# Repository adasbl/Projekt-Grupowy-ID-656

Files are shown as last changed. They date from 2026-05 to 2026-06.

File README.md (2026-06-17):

# Dron kołowy do autonomicznego mapowania terenu

Projekt autonomicznego robota mobilnego opartego na układzie różnicowym (differential drive). Projekt został zrealizowany we współpracy z [Zakładem Automatyki i Urządzeń Pomiarowych AREX Sp. z o.o](https://www.wbgroup.pl/arex/) w ramach Projektu Grupowego na Wydziale ETI Politechniki Gdańskiej.

<div align="center">
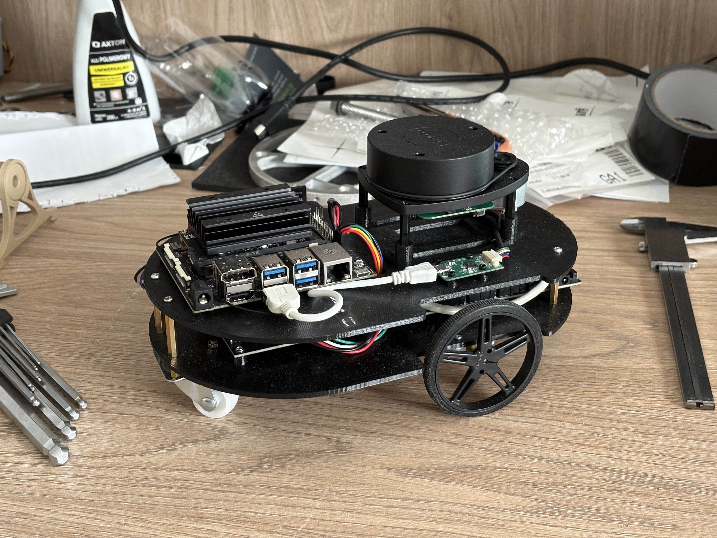
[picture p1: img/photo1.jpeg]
    
</div>

---

Głównym zadaniem robota jest autonomiczna eksploracja nieznanych przestrzeni, budowanie map (SLAM) w czasie rzeczywistym oraz omijanie przeszkód, a także możliwość zdalnego sterowania i monitorowania parametrów telemetrycznych.

<div align="center">
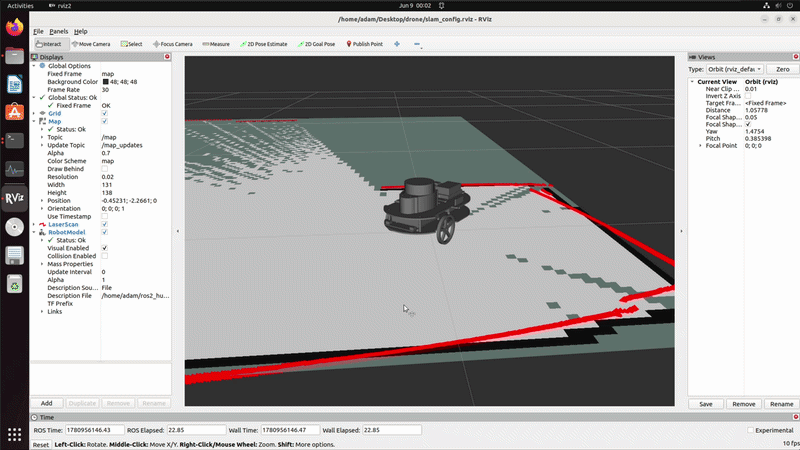
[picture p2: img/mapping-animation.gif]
    
</div>

## 🛠️ Architektura Sprzętowa (Hardware)

System został podzielony na warstwę decyzyjną (High-Level) oraz wykonawczą (Low-Level).

### Jednostka Nadrzędna (High-Level)
* **Komputer:** Nvidia Jetson Nano
* **Zadania:** Przetwarzanie danych ze skanera laserowego, działanie systemu **ROS2 (Humble)** w środowisku Docker, planowanie trajektorii, algorytmy mapowania (SLAM) oraz komunikacja Wi-Fi ze stacją bazową.
* **Sensoryka:** RPlidar A1M8-R6 (skaner laserowy 2D o zasięgu do 12m, komunikacja USB-UART).

### Jednostka Wykonawcza (Low-Level)
* **Mikrokontroler:** STM32L476RG zamontowany na [autorskiej płycie głównej](https://github.com/adasbl/main-controller-pcb.git).
* **Zadania:** Bezpośrednia kontrola silników, sprzętowy regulator PI, akwizycja danych z enkoderów oraz wymiana ramek telemetrycznych z Jetsonem po magistrali UART.
* **Napęd:** Silniki DC 6V Pololu z przekładnią 298:1, sterownik silników DRV8833.
* **Sensoryka:** * Enkodery magnetyczne Pololu 3081 (12 impulsów na obrót).
  * IMU LSM6DSV16X (akcelerometr + żyroskop po I2C do korekcji orientacji).
* **Zasilanie:** Pakiet ogniw 18650 Li-Ion (3.6V) podłączony do modułu UPS Waveshare 18307, który stabilizuje napięcie do 5V (dla Jetsona) i 3.3V (dla logiki STM32 i enkoderów).

<div align="center">
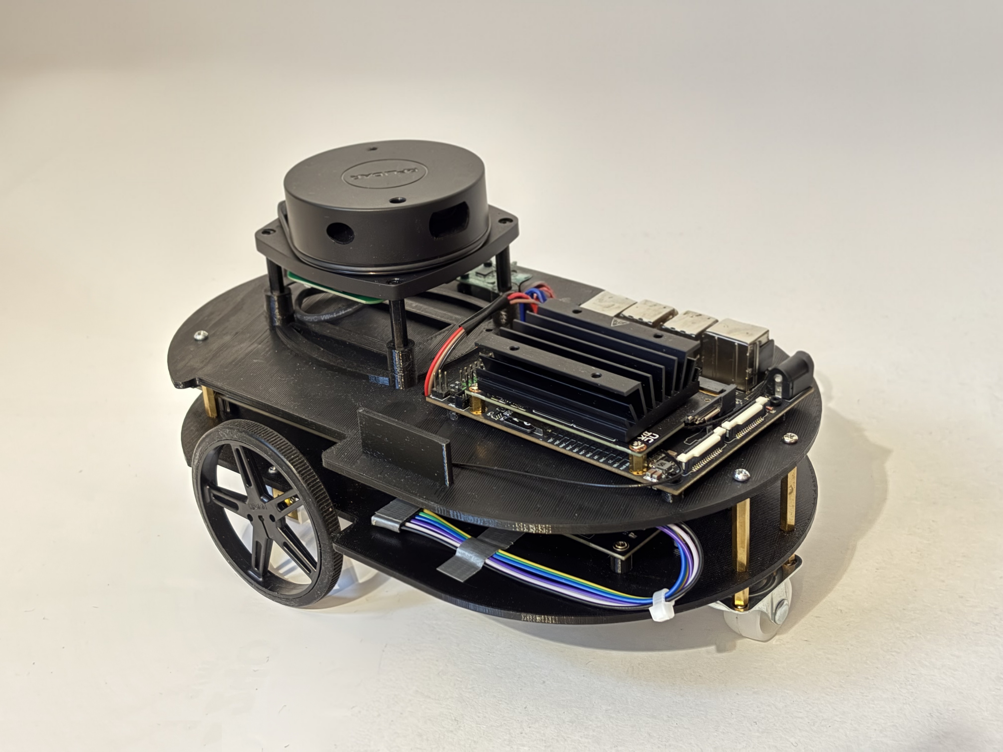
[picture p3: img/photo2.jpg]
    
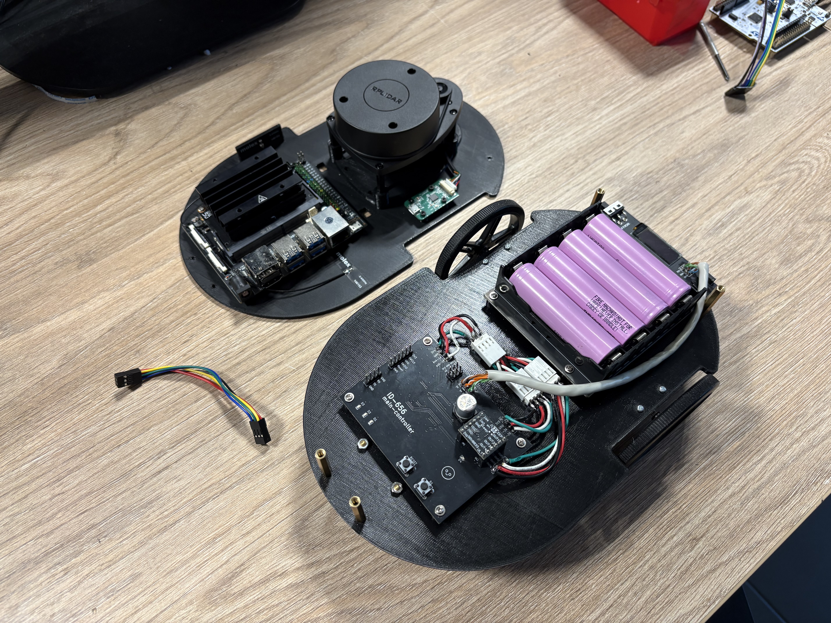
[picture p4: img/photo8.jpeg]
    
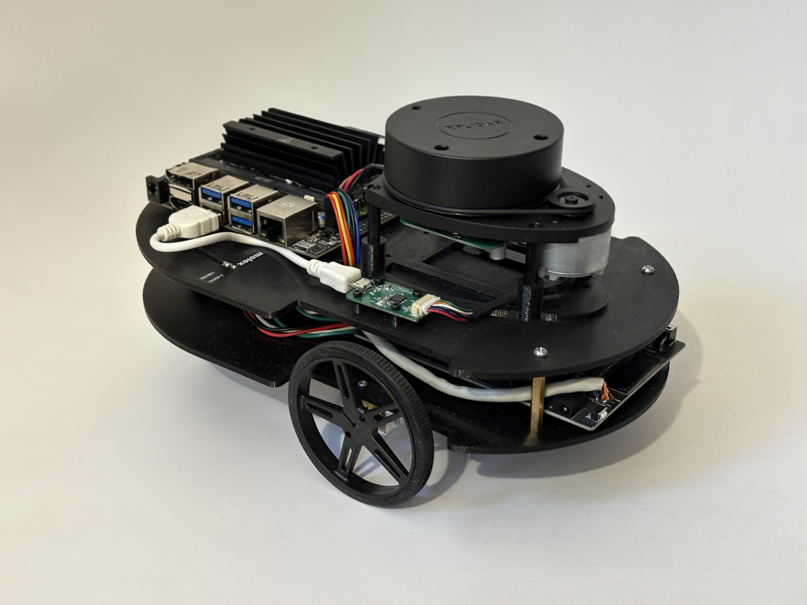
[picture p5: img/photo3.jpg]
    
</div>

---

## 🧠 Architektura Programowa (Software)

### ROS2 & Algorytmy Nawigacji (Jetson Nano)
Oprogramowanie wykorzystuje narzędzia systemu ROS2 do zarządzania węzłami.
* **Mapowanie (SLAM):** Tworzenie map w czasie rzeczywistym na podstawie odczytów z LiDARa oraz enkodometrii.
* **Nawigacja Globalna:** Autorska implementacja algorytmu **A*** (`a_star.py`) wykorzystująca heurystykę odległości Manhattan do wyznaczania najkrótszej ścieżki do celu lub integracja z planerem `GridBased` w Nav2.
* **Nawigacja Lokalna:** Algorytm **DWA (Dynamic Window Approach)** (`dwa.py`) lub `DWBLocalPlanner`, omijający dynamiczne przeszkody na bieżąco, z wbudowanym systemem wykrywania "utknięć" (stuck recovery).
* **Eksploracja:** System potrafi autonomicznie wyszukiwać najdalsze nieodkryte granice mapy (tzw. frontiers) i kierować tam robota (m.in. przy użyciu pakietu `explore_lite`).

### Low-Level Control (STM32)
* Napisany w języku C program z **regulatorem PI**
* Obsługa enkoderów, silników (sterownik `DRV8833`), czujników IMU `LSM6DSV16X` (I2C), przycisków i diód, komunikacji UART
* Komunikacja z Jetsonem odbywa się za pomocą asynchronicznych ramek UART o stałej długości 10 bajtów: `[0xAA, v_lin(float), v_ang(float), 0x55]`.
* Przelicza zadane prędkości na m/s na ticki enkoderów w cyklu 25 ms.

<div align="center">
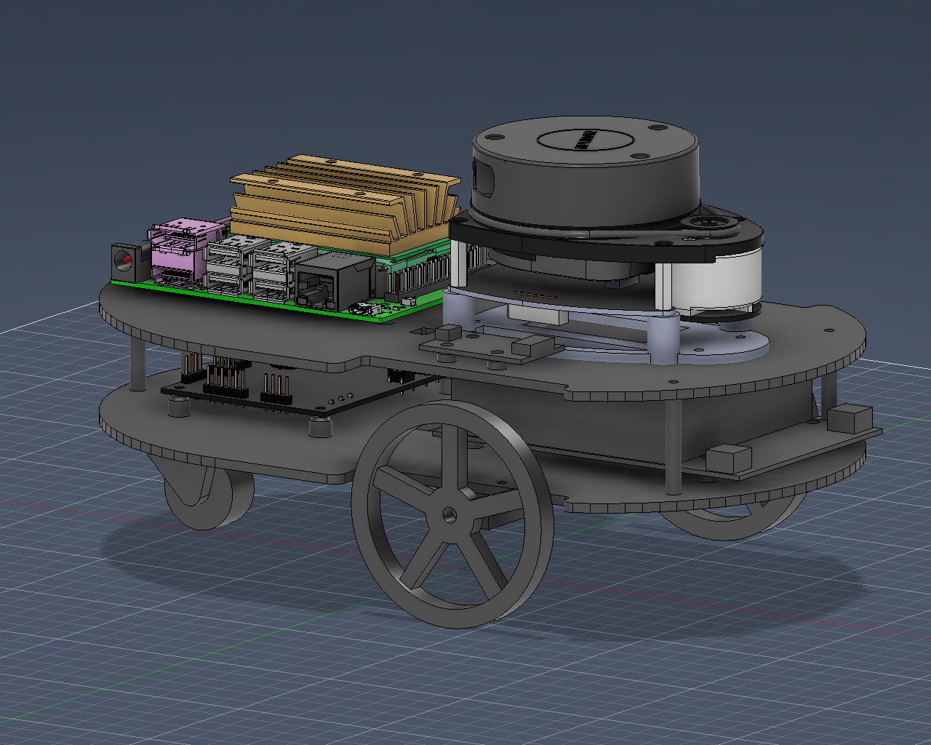
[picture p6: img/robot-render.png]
    
</div>

---

## 💻 Panel Sterowania PC

Do obsługi robota przygotowano dedykowany skrypt uruchamiany na stacji bazowej (`control_panel.py`), który pozwala zarządzać procesami robota przez sieć hotspot robota.

<div align="center">
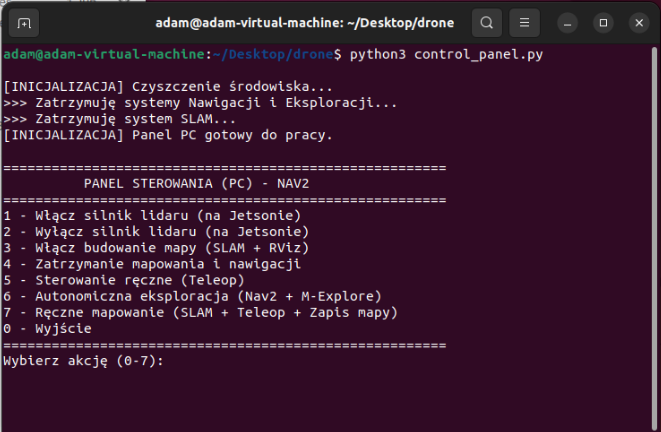
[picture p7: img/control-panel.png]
    
</div>

**Dostępne akcje:**
1. Włącz silnik lidaru
2. Wyłącz silnik lidaru 
3. Budowanie mapy (SLAM + podgląd w RViz). 
4. Zatrzymanie mapowania
5. Sterowanie ręczne (Teleop z klawiatury).
6. **Autonomiczna eksploracja (Nav2 + M-Explore)** <br>
    (SLAM + podgląd w RViz), Robot autonomicznie jeździ po pomieszczeniu do momentu zmapowania całości. Zapisuje mapę i logi do folderu `logs/`.
7. **Ręczne mapowanie** <br>
    (SLAM + podgląd w RViz + Teleop). Ręczna jazda z mapowaniem. Zapisuje mapę i logi do folderu `logs/`.

---

## 📂 Struktura Repozytorium

Struktura plików opiera się na wydzieleniu logiki na poszczególne środowiska wykonawcze:

* `3Dmodels/` - Modele 3D:
  * `platform/` - modele elementów platformy robota.
  * `components/` - modele poszczególnych komponentów.
  * `assembly/` - modele całego robota.
* `code/` - Kod źródłowy i skrypty:
  * `ESP32/` - oprogramowanie eksperymentalne dla ESP32.
  * `jetson/` - węzły ROS2 i algorytmy dla Nvidia Jetson (m.in. `robot_navigation.py`, `a_star.py`, `dwa.py`, `nav2_params.yaml`, `control_panel.py`).
  * `STM32/` - kod C dla mikrokontrolera STM32.
  * `ros_simulation/` & `simulation/` - środowiska do testów algorytmów (np. Gazebo).
* `datasheets/` - Noty katalogowe wykorzystanych podzespołów (np. DRV8833, LSM6DSV16X).
* `docs/` & `docsPG/` - Dokumentacja techniczna (DTP), listy komponentów, bilans mocy.
* `img/` - Zdjęcia projektu, renderów 3D oraz map.
* `pcb/` *(Submoduł)* - Pliki projektu KiCad płyty głównej sterownika.
* `robot-setup/` *(Submoduł)* - Skrypty i konfiguracja początkowa środowiska Docker / Jetson.

---

## 🔗 Powiązane Repozytoria i Odnośniki

* [Oprogramowanie i instrukcja do obsługi robota (ROS2)](https://github.com/matrix1798/robot_sofware.git)
* [Repozytorium autorskiej płytki sterownika wykonawczego (KiCad)](https://github.com/adasbl/main-controller-pcb.git)

## 👥 Zespół Projektowy

* [Adam Błażejewski](https://github.com/adasbl)
* [Mateusz Kuczerowski](https://github.com/matrix1798)
* [Maciej Domeradzki](https://github.com/TofTo23)
* [Krzysztof Toczyński](https://github.com/rolomixedmixed)

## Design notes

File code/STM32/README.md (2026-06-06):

# Opis programów

## Programy głowne do sterownia robotem
### ver1
Sterowanie ruchem i skręcaniem z wykorzystaniem nowych silników i enkoderów (timery w trybie enkodera) – zmiana kierunku jazdy przyciskiem (na przerwaniach). Dla jazdy prosto regulator PID z Anti-Windup oraz stopniowe rozpędzanie robota (soft-start).

### ver2
Sterowanie ruchem z wykorzystaniem niezależnych regulatorów PI dla obu silników wyposażonych w kompensację strefy nieczułości (deadband) oraz Anti-Windup, na podstawie docelowej prędkości (wyrażonej w impulsach enkodera). Zmiana kierunku jazdy (prosto, obrót w miejscu, tył) realizowana przyciskiem na przerwaniach, obsługiwana przez algorytm z kompensacją strefy nieczułości (deadband). 

### ver3
Algorytm jazdy wykorzystujący zadane wartości prędkości kątowej i liniowej (wyrażonych w m/s i rad/s)) - zgodnie z ramką `Twist` odbieraną przerwaniami przez UART. Prędkości automatycznie przeliczane na podstawie zaimplementowanych parametrów fizycznych platformy. Regulatory PI z kompensacją strefy nieczułości (deadband) oraz Anti-Windup.

&nbsp;&nbsp;&nbsp;

## Programy testowe i diagnostyczne
### diodeButtonTest
Program testujący diody oraz przyciski na wbudowanym PCB.

### engineTest
Program uruchamiający koła z konkretnie określoną prędkością  
(bez włączania enkoderów i komunikacji UART).

### enkoderTest
Program inicjujący enkodery i zliczający ich wartości  
(do użycia w trybie debugowania).

### uartTest
Program testujący komunikację UART pomiędzy Jetson Nano a STM32 (uart3). Dane są printowane do konsoli (uart2)  
(do użycia z nucleo, płytka wbudowana nie ma wyprowadzone uart2).

### gyroConsole
Program do obsługi i testowania żyroskopu przez konsolę.

### sterowanieESP
Jazda w zadanym kierunku poprzez ESP32 z wykorzystaniem silników i enkoderów.

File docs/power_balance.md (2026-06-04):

# Robot Power Budget

## 1. Available Power

| Power Supply Module | Output Voltage | Maximum Output Current | Total Available Power |
| :--- | :--- | :--- | :--- |
| **Waveshare UPS Module 3S** | 5 V | 5 A | **25.00 W** |

---

## 2. Power Consumption Calculation – Component Breakdown

Maximum (peak) power demand of all components.

| Component | Peak Power | Notes / Calculation Basis |
| :--- | :--- | :--- |
| **NVIDIA Jetson Nano** | 5.00 W or 10.00 W | Depending on the selected operating mode (nvpmodel). |
| **Intel 8265NGW** | ~2.00 W | Active Wi-Fi/BT transmission under load. |
| **RPLiDAR A1** | 1.75 W | Peak consumption during scanner startup. |
| **Camera and Sensors** | 0.50 W | Continuous operation of vision and sensors. |
| **STM32L476RGT6** | ~0.10 W | Maximum margin for microcontroller logic. |
| **Pololu Motor (Left)** | ~2.16 W | LP series: 6 V × 0.36 A (powered at 5 V). |
| **Pololu Motor (Right)** | ~2.16 W | LP series: 6 V × 0.36 A (powered at 5 V). |
| **DRV8833 Driver** | Negligible | Heat losses (minor at low current). |

---

## 3. Load Summary

Total consumption in two Jetson operating modes, assuming maximum load.

| Parameter | Variant 1: Jetson in 5W mode | Variant 2: Jetson in 10W mode |
| :--- | :--- | :--- |
| **Peak Logic Consumption** | ~9.35 W | ~14.35 W |
| **Peak Drive Consumption** | ~4.32 W | ~4.32 W |
| **TOTAL CONSUMPTION (Peak)**| **~13.67 W** | **~18.67 W** |
| **Power Supply Limit (UPS)** | 25.00 W | 25.00 W |
| **Remaining Power Margin** | **11.33 W (45%)** | **6.33 W (25%)** |

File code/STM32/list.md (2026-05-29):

# Opis programów

## sterowanieESP
Jazda w zadanym kierunku poprzez ESP32 z wykorzystaniem silników i enkoderów.

## diodeButtonTest
Program testujący diody oraz przyciski na wbudowanym PCB.

## engineTest
Program uruchamiający koła z konkretnie określoną prędkością  
(bez włączania enkoderów i komunikacji UART).

## enkoderTest
Program inicjujący enkodery i zliczający ich wartości  
(do użycia w trybie debugowania).

## uartTest
Program testujący komunikację UART.

## gyroConsole
Program do obsługi i testowania żyroskopu przez konsolę.

## ver1
Sterowanie ruchem i skręcaniem z wykorzystaniem nowych silników i enkoderów (timery w trybie enkodera) – zmiana kierunku jazdy przyciskiem (na przerwaniach). Dla jazdy prosto regulator PID oraz stopniowe rozpędzanie robota (soft-start).

## ver2
Algorytm jazdy wykorzystujący zadane wartości prędkości kątowej i liniowej, zgodnie z ramką `Twist` odbieraną przerwaniami przez UART.

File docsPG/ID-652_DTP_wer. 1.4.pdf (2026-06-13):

SZP{akronim projektu} | Dokumentacja techniczna projektu | Projekt grupowy, WETI PG
PG_WETI_DTP_wer._1.00 | 1 / 11 | Data 13.06.2026 14:57:47

### Dokumentacja projektu grupowego

# Dokumentacja techniczna projektu

Wydział Elektroniki, Telekomunikacji i Informatyki

Politechnika Gdańska

{wersja dokumentu wzorcowego: wersja 1/2026}

Nazwa i akronim projektu: Dron kołowy do autonomicznego mapowania terenu | Zleceniodawca: Zakład Automatyki i Urządzeń Pomiarowych AREX Sp. z o.o.
Numer zlecenia: ID-656 | Kierownik projektu: Adam Błażejewski | Opiekun projektu: prof. Bogdan Pankiewicz
Nazwa dokumentu/akronim: Dokumentacja techniczna projektu – DTP | Nr wersji: 1.4
Odpowiedzialny za dokument: Maciej Domeradzki | Data pierwszego sporządzenia: 23.01.2026

Data ostatniej aktualizacji: 13.06.2026

Studia I stopnia, inżynierskie
Semestr realizacji Projektu grupowego: 1 i 2

Historia zmian

Wersja | Opis modyfikacji | Rozdział / strona | Autor modyfikacji | Data
0.5 | Wstępna wersja dokumentacji. | Całość | Kuczerowski, Mateusz | 23.01.2026
0.6 | Przeredagowanie i dodanie zdjęć | Całość | Adam Błażejewski, Maciej Domeradzki | 24.01.2026
0.7 | Uzupełnienie treści | Sekcja 2 | Krzysztof Toczyński Mateusz Kuczerowski | 28.01.2026
0.8 | Poprawki i formatowanie | Strona tytułowa | Adam Błażejewski | 30.01.2026
1.0 | Aktualizacja zgodnie ze stanem rzeczywistym przed zakończeniem projektu | Całość | Maciej Domeradzki | 03.06.2026
1.1 | Opisy komunikacji oraz elektroniki | Sekcja 2 | Adam Błażejewski | 05.06.2026
1.2 | Dodanie załączników | Sekcja 3 | Adam Błażejewski | 06.06.2026
1.3 | Uzupełnienie spisu treści | Spis treści | Maciej Domeradzki | 11.06.2026
1.4 | Uzupełnienei zdjęć | Sekcja 2 | Adam Błażejewski | 13.06.2026

PG_WETI_DTP_wer._1.00 | 2 / 11 | Data 13.06.2026 14:57:47

## Spis treści

1. Wprowadzenie - o dokumencie | 3
1.1 | Cel dokumentu | 3
1.2 | Zakres dokumentu | 3
1.3 | Odbiorcy | 3
1.4 | Terminologia | 3
2 | Dokumentacja techniczna projektu | 3
2.1 | Architektura systemu | 3
2.2 | Warstwa mechaniczna | 4
2.3 | Warstwa elektroniczna | 4
2.3.1 | Zasilanie | 5
2.3.2 | Sterownik główny (komputer wykonawczy) | 5
2.3.3 | Schemat podłączeń elektrycznych | 7
2.3.4 | Wykaz pozostałych komponentów | 7
2.4 | Warstwa programowa (Software) | 8
2.4.1 | Sterowanie silnikami. | 8
2.4.2 | Obsługa komunikacji. | 8
2.4.3 | Algorytm autonomicznej jazdy i nawigacji | 9
3 | Załączniki | 11

PG_WETI_DTP_wer._1.00 | 3 / 11 | Data 13.06.2026 14:57:47

### 1. Wprowadzenie - o dokumencie

### 1.1 Cel dokumentu

Celem | dokumentu jest | udokumentowanie | informacji | dotyczących | produktu, jego | cech
funkcjonalnych, parametrów technicznych, schematów blokowych, oprogramowania, wyników działania, zdjęć produktu, pomiarów, testów oraz innych elementów wymaganych przez opiekuna i klienta.

### 1.2 Zakres dokumentu

Dokument obejmuje opis techniczny projektu autonomicznego robota mobilnego. Zakres opracowania zawiera:
- Charakterystykę architektury systemu (podział na warstwę sprzętową i programową).
- Schemat połączeń elektrycznych i opis wykorzystanych podzespołów (STM32, Jetson Nano, sensoryka).
- Opis algorytmów sterowania.
- Noty katalogowe użytych komponentów takich jak: DVR8833, LSM6DSV16X
- Schemat i działanie płytki custom PCB
Dokument nie obejmuje szczegółowej dokumentacji wewnętrznej gotowych modułów (np. kart katalogowych producenta układu Jetson Nano), a jedynie sposób ich integracji w systemie.

### 1.3 Odbiorcy

Głównymi adresatami dokumentu są:
- Opiekun projektu: Prof. Bogdan Pankiewicz oceniający zgodność projektu z założeniami.
- Zespół projektowy: Dokument stanowi bazę wiedzy techniczej niezbędną do dalszego rozwoju i serwisowania robota.
- Użytkownicy końcowi: Osoby zainteresowane projektem należącymi do stuneckiego koła naukowego CHIP.

### 1.4 Terminologia

Lista użytych skrutów językowych wykorzystanych w dokumentacji projektu:
- MCU (Microcontroller Unit): Mikrokontroler sterujący niskopoziomowy, w projekcie STM32.
- ROS (Robot Operating System): Otwartoźródłowy zestaw bibliotek i narzędzi do tworzenia oprogramowania dla robotów.
- LIDAR (Light Detection and Ranging): Metoda pomiaru odległości poprzez oświetlanie celu światłem laserowym; w dokumencie odnosi się do skanera laserowego 2D.
- IMU (Inertial Measurement Unit): Jednostka inercyjna integrująca akcelerometr i żyroskop.
- SLAM (Simultaneous Localization and Mapping): Algorytm jednoczesnego lokalizowania robota i budowania mapy otoczenia.
- PWM (Pulse-Width Modulation): Modulacja szerokości impulsu, wykorzystywana do sterowania mocą silników.
- UART (Universal Asynchronous Receiver-Transmitter): Interfejs komunikacj szeregowej.

### 2 Dokumentacja techniczna projektu

Dokumentację techniczną możemy podzielić na poniższe podpunkty:

### 2.1 Architektura systemu

W tym rozdziale przedstawiono ogólną koncepcję działania robota. System został podzielony na dwie główne warstwy: decyzyjną (High-Level) oraz wykonawczą (Low-Level).
- Jednostka nadrzędna: Komputer Nvidia Jetson Nano, odpowiedzialny za przetwarzanie danych z LIDAR-u, działanie systemu ROS oraz algorytmy mapowania.
- Jednostka wykonawcza: Układ sterowania niskopoziomowego oparty na mikrokontrolerze STM32, odpowiedzialny za bezpośrednią kontrolę pracy silników, akwizycję danych z enkoderów oraz obsługę czujników inercyjnych (IMU).
- Komunikacja między powyższymi układami odbywa się za pomocą interfejsu UART.

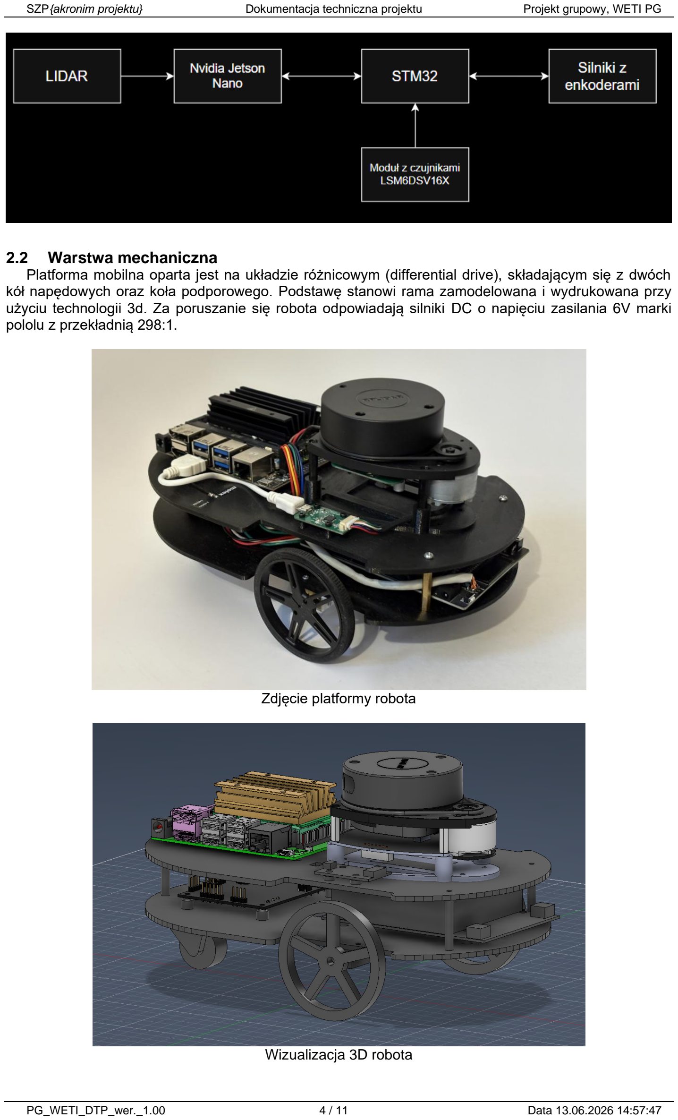
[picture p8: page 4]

PG_WETI_DTP_wer._1.00 | 4 / 11 | Data 13.06.2026 14:57:47

### 2.2 Warstwa mechaniczna

Platforma mobilna oparta jest na układzie różnicowym (differential drive), składającym się z dwóch kół napędowych oraz koła podporowego. Podstawę stanowi rama zamodelowana i wydrukowana przy użyciu technologii 3d. Za poruszanie się robota odpowiadają silniki DC o napięciu zasilania 6V marki pololu z przekładnią 298:1.

Zdjęcie platformy robota

Wizualizacja 3D robota

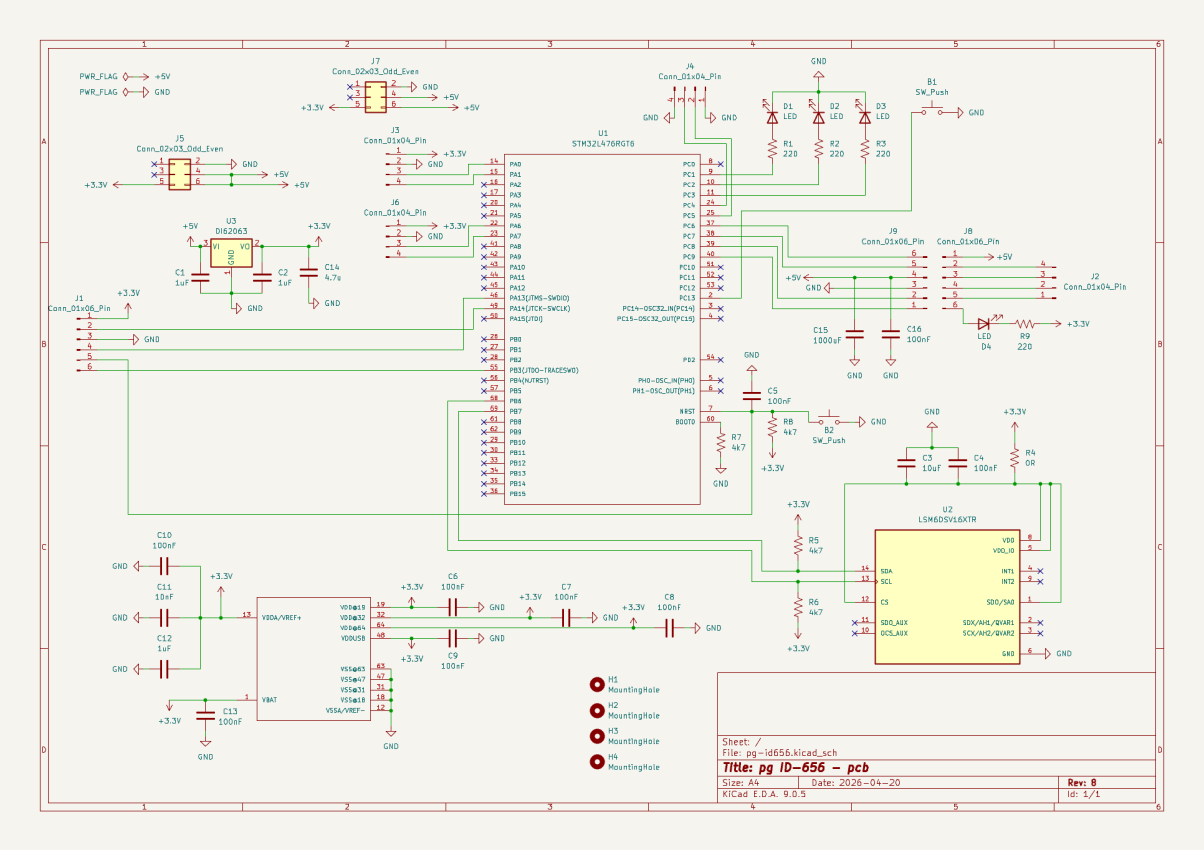
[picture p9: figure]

PG_WETI_DTP_wer._1.00 | 5 / 11 | Data 13.06.2026 14:57:47

### 2.3 Warstwa elektroniczna

Opis warstwy elektronicznej projektu.

### 2.3.1 Zasilanie

Układ elektroniczny zasilany jest z pakietu ogniw 18650 Li-Ion o napięciu nominalnym 3,6 V. Napięcie to jest stabilizowane do poziomu 5 V za pośrednictwem dedykowanego modułu zasilającego Waveshare 18307.
Moduł ten zasila bezpośrednio płytkę sterownika, która odpowiada za dostarczanie energii do silników wykonawczych. Dodatkowo na płytce sterownika następuje konwersja napięcia do poziomu 3,3 V, do zasilania logiki własnej układu, sterownika silników DRV8833 oraz enkoderów.

### 2.3.2 Sterownik główny (komputer wykonawczy)

Do kontroli pracy warstwy wykonawczej wykorzystywany jest dedykowany obwód drukowany (PCB), zaprojektowany w KiCad. Jednostką centralną podsystemu jest mikrokontroler STM32L476RG. Na płytce bazowej zintegrowano dedykowane interfejsy połączeniowe dla enkoderów, silników, sekcji zasilania oraz magistralę UART przeznaczoną do asynchronicznej wymiany danych z komputerem nadrzędnym. Architektura sprzętowa przewiduje również gniazdo do bezpośredniego montażu modułowego (w układzie tzw. kanapkowym) sterownika DRV8833. Układ został wyposażony w cyfrowy czujnik inercyjny (IMU) typu LSM6DSV16X zakcelerometrem oraz żyroskopem, realizujący komunikację za pośrednictwem magistrali I2C. Strukturę sprzętową uzupełniają elementy interfejsu użytkownika oraz układy diagnostyczne: przycisk resetu, przycisk programowalny, dioda LED sygnalizująca stan awarii sterownika silników oraz trzy programowalne diody statusowe.

Schemat ideowy układu sterownika wykonawczego (opracowany w środowisku KiCad)

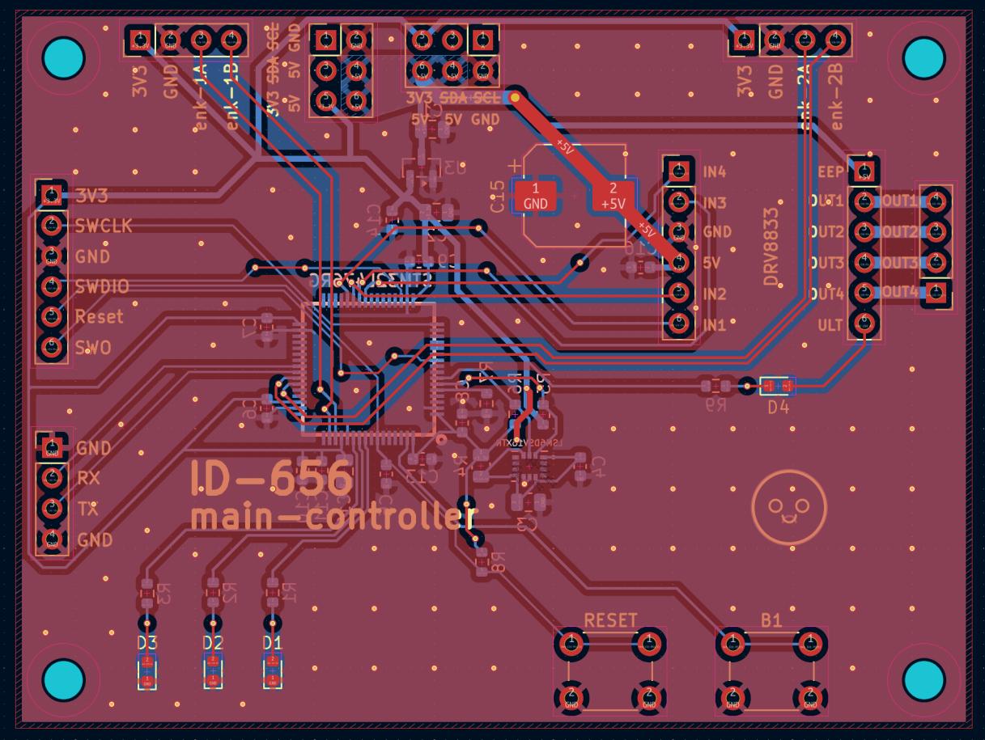
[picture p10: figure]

PG_WETI_DTP_wer._1.00 | 6 / 11 | Data 13.06.2026 14:57:47

Projekt obwodu drukowanego PCB (opracowany w środowisku KiCad)

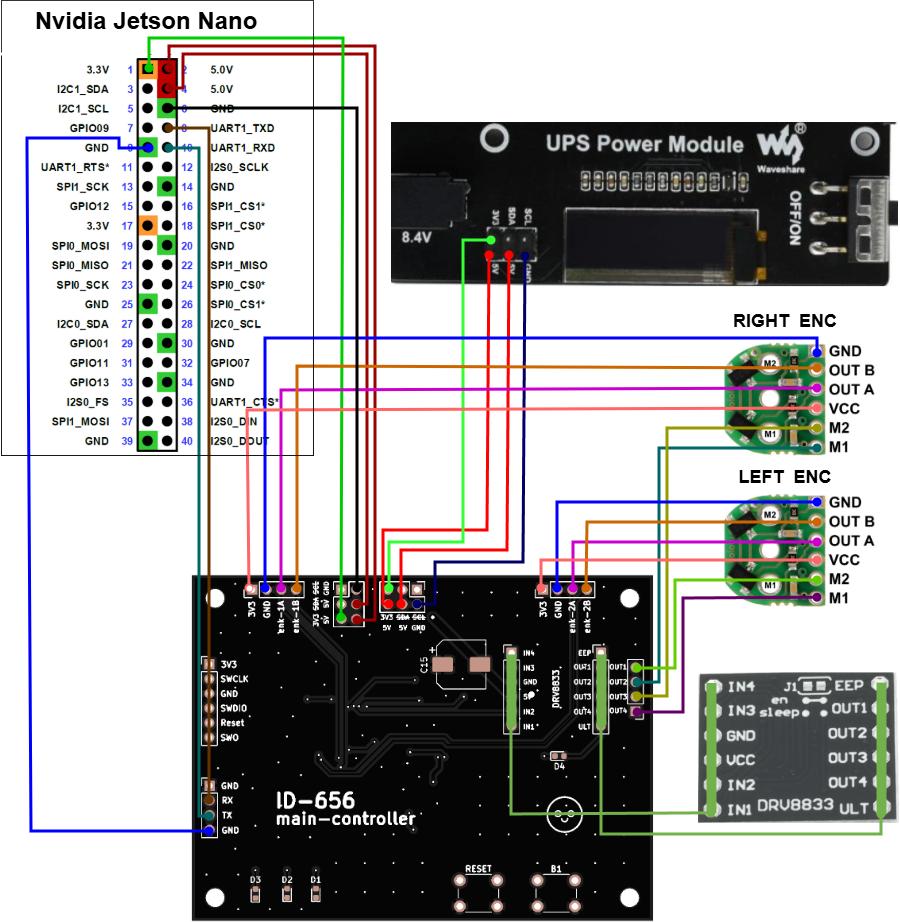
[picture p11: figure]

PG_WETI_DTP_wer._1.00 | 7 / 11 | Data 13.06.2026 14:57:47

### 2.3.3 Schemat podłączeń elektrycznych

Poniższy | schemat | prezentuje | sposób | połączenia | urządzeń | elektroniczych.

### 2.3.4 Wykaz pozostałych komponentów

- Sterownik silników: DRV8833
- Sensoryka:
-LIDAR: RPlidar A1M8-R6, skaner laserowy 2D o zasięgu 12m
-IMU: LSM6DSV16X akcelerometr i żyroskop wykorzystywany do korekcji orientacji robota. -Enkodery: zestaw magnetycznych enkoderów kwadraturowych Pololu 3081, 12 impulsów na obrót

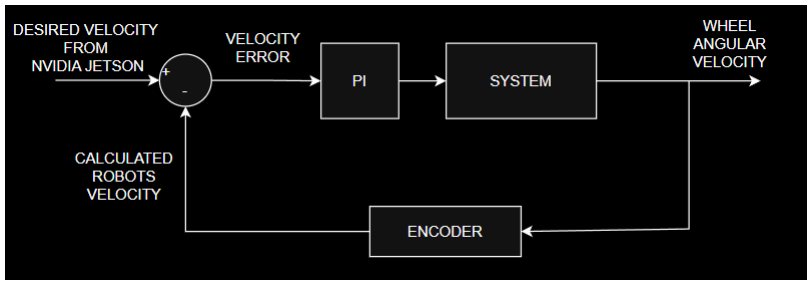
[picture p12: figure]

PG_WETI_DTP_wer._1.00 | 8 / 11 | Data 13.06.2026 14:57:47

### 2.4 Warstwa programowa (Software)

Oprogramowanie mikrokontrolera zostało napisane w języku C przy użyciu środowiska STM32CubeIDE. Głównym zadaniem układu jest realizacja pętli sterowania prędkością silników.
Na komputerze Jetson Nano dokonano instalcji ROS2 dystrybucji Humble za pomoca dokera.

Panel kontrolny do zdanlego sterowania robotem

2.4.1 Sterowanie silnikami.
Prędkość obrotowa regulowana jest poprzez sygnał PWM. Mikrokontroler Stm32 otrzymuje docelowe wartości prędkości liniowej i obrotowej wyznaczone przez algorytm działający na jednostce nadrzędnej Nvidia jetson nano. W celu regulacji zaimplementowany został kontroler PI, który pozwala na precyzyjne sterowanie dzięki śledzeniu sygnału z enkoderów i korekcji błędu.

2.4.2 Obsługa komunikacji.
Komunikacja pomiędzy komputerem wykonawczym (mikrokontrolerem STM32) a komputerem nadrzędnym Jetson Nano odbywa się za pomocą interfejsu UART. Wymiana informacji sterujących bazuje na przesyłaniu danych w formacie Twist (standardu w systemie ROS). Mikrokontroler odbiera z jednostki nadrzędnej zadane prędkości liniowe i kątowe za pomocą stałej, 10-bajtowej ramki danych.

Oprócz komunikacji z układem wykonawczym, komputer Jetson Nano odpowiada za wymianę danych z czujnikiem Lidar. Skaner laserowy 2D (RPlidar A1) komunikuje się za pośrednictwem złącza USB, wykorzystując w tym celu zewnętrzny adapter UART-USB.

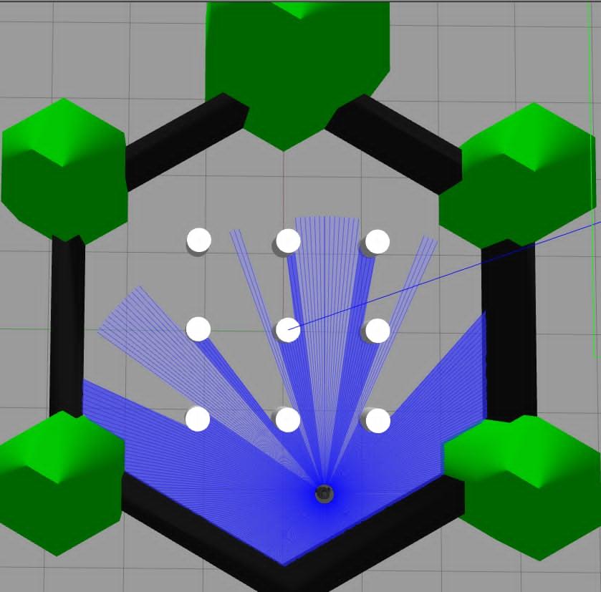
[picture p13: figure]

PG_WETI_DTP_wer._1.00 | 9 / 11 | Data 13.06.2026 14:57:47

Z kolei łączność komputera Jetson Nano ze stacją bazową (laptopem operatorskim) realizowana jest bezprzewodowo w standardzie Wi-Fi. W celu zapewnienia stabilnej transmisji i odpowiedniego zasięgu radiowego, minikomputer został doposażony w dedykowaną kartę sieciową oraz zewnętrzne anteny o wysokim zysku energetycznym. Rozwiązanie to umożliwia zdalny monitoring parametrów telemetrycznych robota, wizualizację danych mapowania w czasie rzeczywistym oraz bezprzewodowe przesyłanie komend w trybie sterowania manualnego.

### 2.4.3 Algorytm autonomicznej jazdy i nawigacji

Program obsługuje dwa tryby pracy robota: manualny oraz automatyczny. W trybie manualnym możliwe jest podanie punktu docelowego, do którego robot ma dojechać, unikając przeszkód na bieżąco.
Tryb automatyczny pozwala na autonomiczną eksplorację obszaru w celu wsparcia zewnętrznego algorytmu SLAM w tworzeniu mapy. Odbywa się to wg poniższego algorytmu:
- Technologia SLAM tworzy mapę na podstawie odczytów z LiDARa.
- Robot pobiera z systemu gotową mapę i przetwarza ją na mapę binarną.
- Na jej podstawie wyszukuje najdalszy, nieodkryty punkt znajdujący się na styku z punktami wolnymi od przeszkód i przyjmuje go za tymczasowy cel.
- Za pomocą algorytmu A* wyznacza do niego najkrótszą ścieżkę globalną na siatce.
- Podążając do celu, robot omija dynamiczne przeszkody w czasie rzeczywistym wykorzystując algorytm DWA (Dynamic Window Approach) na podstawie bieżących odczytów z LiDARa.
- Dodatkowo stale monitoruje, czy nie utknął w miejscu.
- Powtarza powyższe sekwencje do momentu, w którym mapa nie posiada już żadnych nieodkrytych krawędzi.

Symulacja otoczenia i robota w środowisku Gazebo

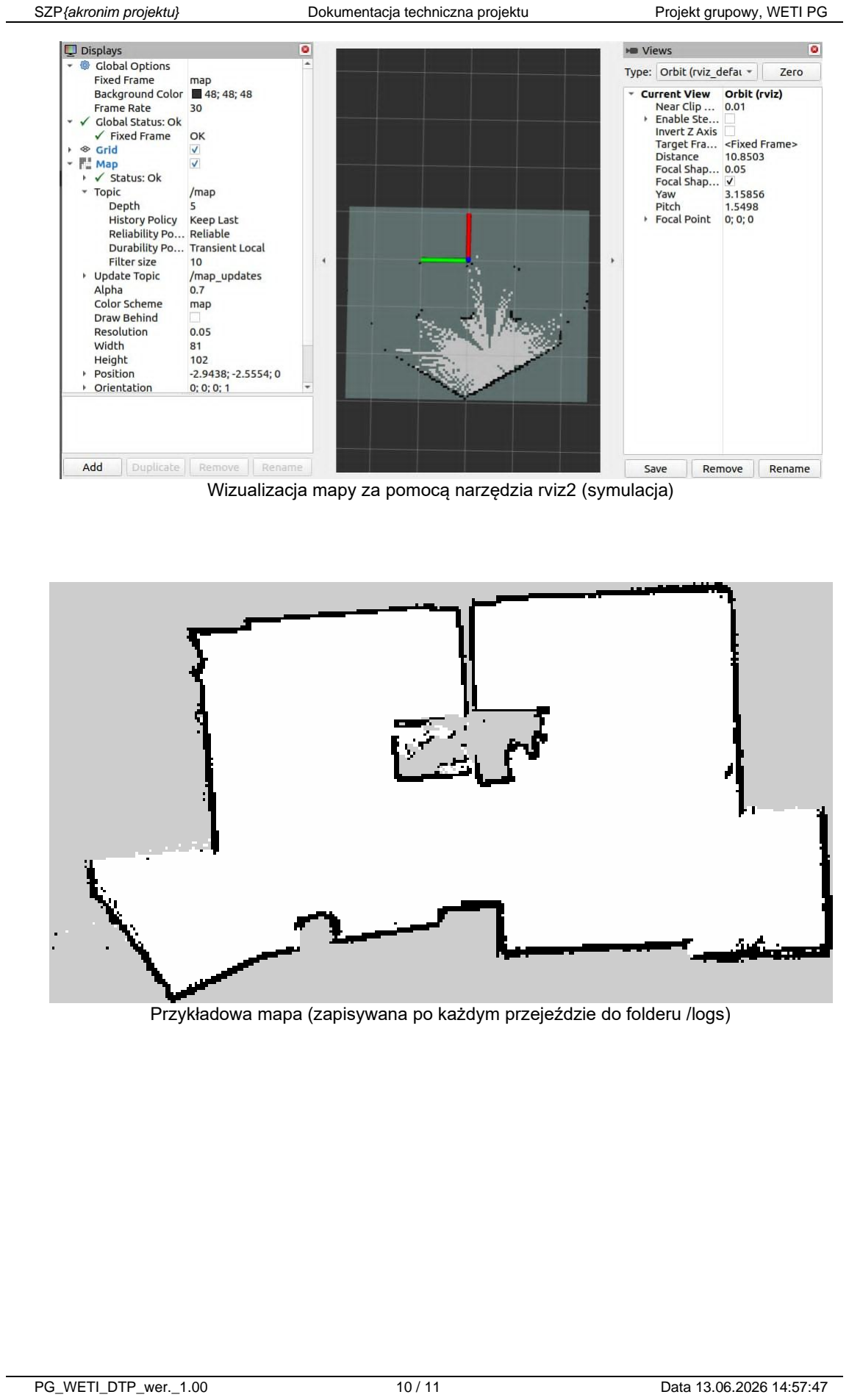
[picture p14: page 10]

PG_WETI_DTP_wer._1.00 | 10 / 11 | Data 13.06.2026 14:57:47

Wizualizacja mapy za pomocą narzędzia rviz2 (symulacja)

Przykładowa mapa (zapisywana po każdym przejeździe do folderu /logs)

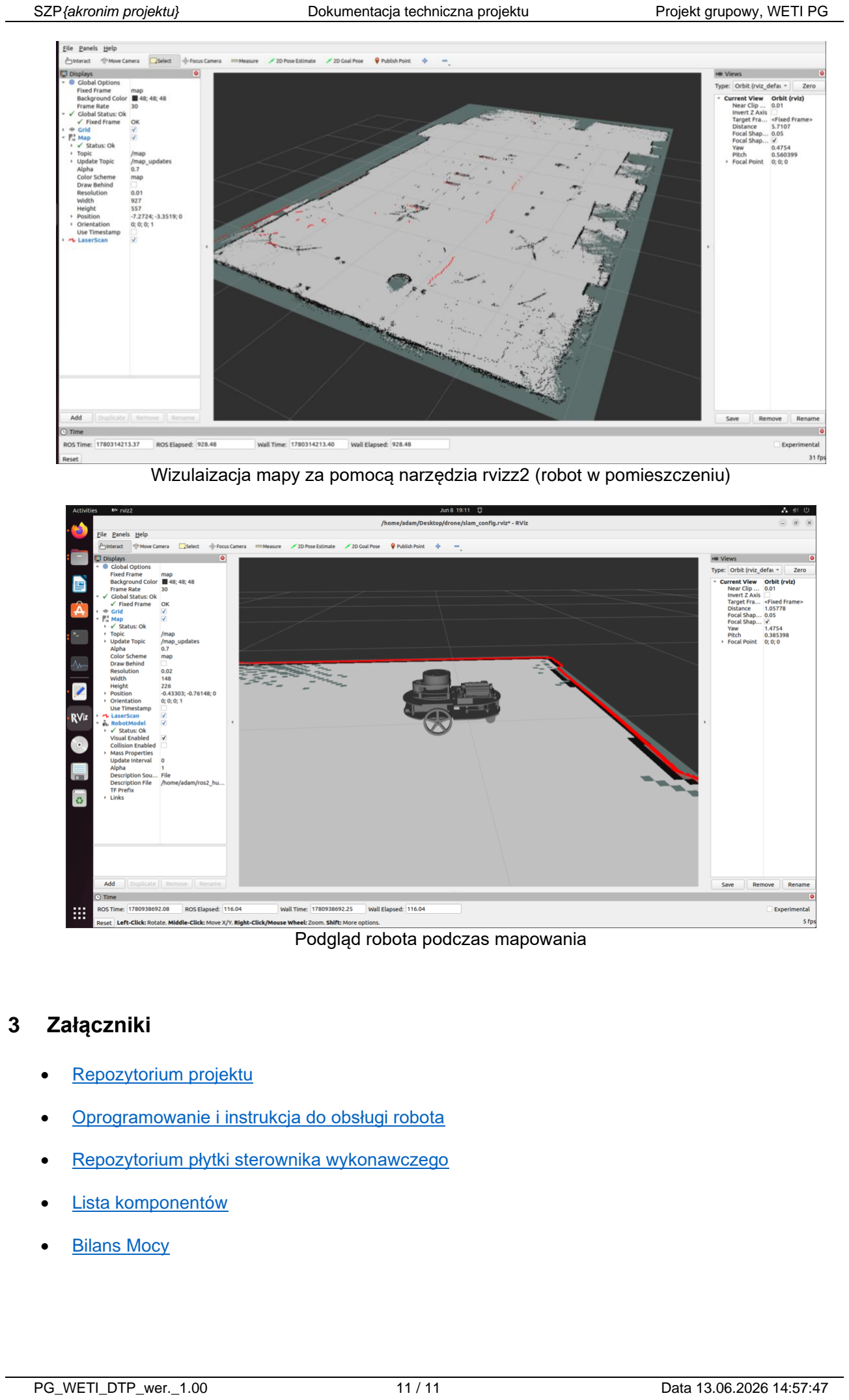
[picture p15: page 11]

PG_WETI_DTP_wer._1.00 | 11 / 11 | Data 13.06.2026 14:57:47

Wizulaizacja mapy za pomocą narzędzia rvizz2 (robot w pomieszczeniu)

Podgląd robota podczas mapowania

### 3 Załączniki

- Repozytorium projektu (https://github.com/adasbl/Projekt-Grupowy-ID-656.git)
- Oprogramowanie i instrukcja do obsługi robota (https://github.com/matrix1798/robot_sofware.git)
- Repozytorium płytki sterownika wykonawczego (https://github.com/adasbl/main-controller-pcb.git)
- Lista komponentów (https://github.com/adasbl/Projekt-Grupowy-ID-656/blob/main/docs/component_list.md)
- Bilans Mocy (https://github.com/adasbl/Projekt-Grupowy-ID-656/blob/main/docs/power_balance.md)

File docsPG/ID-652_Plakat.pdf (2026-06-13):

PLAKAT INFORMACYJNY PROJEKTU GRUPOWEGO – GRUDZIEŃ 2025

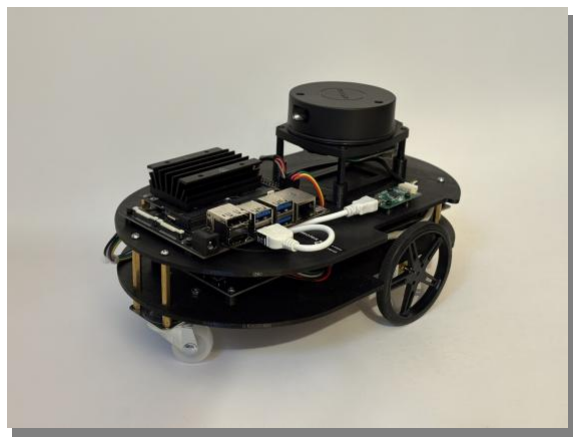
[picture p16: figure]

WYDZIAŁ ELEKTRONIKI, TELEKOMUNIKACJI I INFORMATYKI POLITECHNIKI GDAŃSKIEJ

KATEDRA PEŁNA NAZWA

Zespół projektowy: ID-656 | 1. Adam Błażejewski -kierownik 2. Maciej Domeradzki 3. Krzysztof Toczyński 4. Mateusz Kuczerowski
Opiekun: | Prof. Bogdan Pankiewicz
Klient: | Zobacz z zewnątrz Zakład Automatyki i Urządzeń Pomiarowych AREX Sp. z o.o.
Data zakończenia: | 30.06.2026
Słowa kluczowe: | ROS2,Nvidia Jetson Nano, STM32, RPLidar

TEMAT PROJEKTU:

Dron kołowy do autonomicznego mapowania terenu

CELE I ZAKRES PROJEKTU:
1.Zapoznanie się z literaturą i dokumentacją techniczną projektu.

2.Zakup niezbędnych elementów projektowych.

3.Budowa jeżdżącej platformy kołowej sterowanej mikrokontrolerem STM32.

4.Integracja LIDAR-u z komputerem Nvidia Jetson Nano w środowisku ROS oraz napisanie programu sterującego skanerem.

5.Implementacja systemu sterowania mocą silników.

6.Stworzenie algorytmu interpretacji danych pomiarowych w ROS.

7.Konfiguracja połączenia komunikacyjnego między Jetsonem Nano a STM32.

8.Zaprojektowanie i wydrukowanie obudowy robota w technologii druku 3D.

9.Opracowanie algorytmów autonomicznej pracy: mapowanie przestrzeni i lokalizacja.

TEAM PROJECT INFORMATION FOLDER – DECEMBER 2025

FACULTY OF ELECTRONICS, TELECOMMUNICATIONS AND INFORMATICS, GDANSK UNIVERSITY OF TECHNOLOGY

OSIĄGNIĘTE REZULTATY:

- Zbudowano układ różnicowy, którego rama została zamodelowana i wydrukowana przy użyciu technologii 3D.
- Zaprojektowano autorski obwód drukowany (PCB) w środowisku KiCad, integrujący mikrokontroler STM32L476RG, sterowniki silników DRV8833 oraz czujnik inercyjny LSM6DSV16X.
- Pomyślnie wdrożono algorytm sterowania prędkością silników (kontroler PI) z wykorzystaniem sprzężenia zwrotnego z enkoderów.
- Na jednostce Jetson Nano zainstalowano system ROS2 (dystrybucja Humble) z użyciem środowiska Docker.
- Zaimplementowano obsługę trybu automatycznej eksploracji obszaru we współpracy z zewnętrznym algorytmem SLAM na podstawie odczytów z LiDARa.

CECHY CHARAKTERYSTYCZNE ROZWIĄZANIA, KIERUNKI DALSZYCH PRAC: Cechy charakterystyczne: Zaawansowana nawigacja autonomiczna — robot wyznacza najkrótszą globalną ścieżkę przy pomocy algorytmu A* na wygenerowanej mapie binarnej. Dodatkowo wykorzystuje algorytm DWA (Dynamic Window Approach) do omijania dynamicznych przeszkód w czasie rzeczywistym. Umożliwiono zdalny monitoring telemetryczny oraz wizualizację mapy przez Wi-Fi z użyciem programu rviz2

TEAM PROJECT INFORMATION FOLDER – DECEMBER 2025
DEPARTMENT FULL NAME

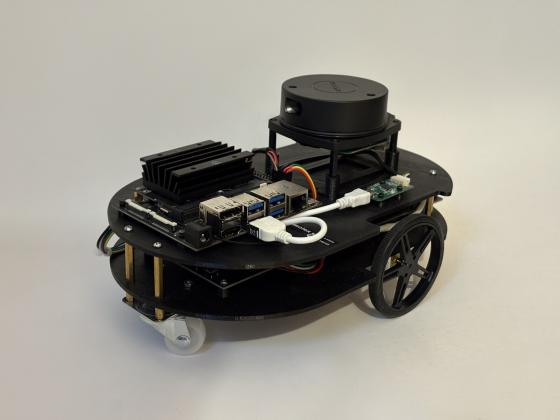
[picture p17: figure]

Project team: ID-656 | 1. Adam Błażejewski - leader 2. Maciej Domeradzki 3. Krzysztof Toczyński 4. Mateusz Kuczerowski
Supervisor: | Prof. Bogdan Pankiewicz
Client: | Zakład Automatyki i Urządzeń Pomiarowych AREX Sp. z o.o.
Date: | 30.06.2026
Key words: | ROS2,Nvidia Jetson Nano, STM32, RPLidar

PROJECT TITLE:

Drone for autonomous terrain mapping

OBJECTIVES AND SCOPE:
1. Review of the literature and technical documentation related to the project.
2. Purchase of the necessary project components.
3. Construction of a mobile platform controlled by an STM32 microcontroller.
4. Integration of a LIDAR sensor with an Nvidia Jetson Nano using the ROS environment and development of control software for the scanner.
5. Implementation of a motor power control system.
6. Development of an algorithm for interpreting measurement data in ROS.
7. Configuration of the communication interface between the Jetson Nano and the STM32.
8. Design and 3D printing of the robot enclosure.
9. Development of algorithms for autonomous operation: spatial mapping and localization.

TEAM PROJECT INFORMATION FOLDER – DECEMBER 2025
RESULTS:
- Constructed a differential drive platform featuring a custom 3D printed frame.
- Designed a custom printed circuit board (PCB) using KiCad, integrating an STM32L476RG microcontroller, DRV8833 motor drivers, and an LSM6DSV16X inertial sensor.
- Successfully implemented a PI controller for motor speed regulation, utilizing encoder feedback.
- Deployed the ROS2 Humble operating system via Docker on the Jetson Nano computing unit.
- Implemented an automated exploration mode working in tandem with a SLAM algorithm based on LiDAR data.

MAIN FEATURES, FUTURE WORKS:
Main features: Advanced autonomous navigation — the robot calculates the shortest global path using the A* algorithm on a processed binary map. Furthermore, it uses the Dynamic Window Approach (DWA) algorithm to dynamically avoid obstacles in real-time. Remote telemetry monitoring and map visualization via Wi-Fi are fully supported using rviz2.

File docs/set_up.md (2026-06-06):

##  Wymagania wstępne

Zanim rozpoczniesz, upewnij się, że Twój komputer spełnia następujące wymagania:
* **System operacyjny:** Linux (zalecany Ubuntu 22.04 LTS).
* **Narzędzia:** Zainstalowany system kontroli wersji `git`.
* **Połączenie sieciowe:** Komputer PC musi połączyć się z robotem poprzez wygenerowany hotspot drona 'jetson_hotspot' (hasło: `jetson_hotspot`).

---

##  Instrukcja instalacji krok po kroku

### Krok 1: Instalacja ROS 2 Humble
Jeśli nie masz jeszcze zainstalowanego systemu ROS 2, wykonaj pełną instalację w wersji **Humble** (Desktop) zgodnie z oficjalną dokumentacją:
 [Oficjalna instrukcja instalacji ROS 2 Humble (Ubuntu Debs)](https://docs.ros.org/en/humble/Installation/Ubuntu-Install-Debs.html)

Po poprawnej instalacji upewnij się, że środowisko ładuje się poprawnie (najlepiej dodać komendę `source /opt/ros/humble/setup.bash` do pliku `~/.bashrc`).

### Krok 2: Instalacja wymaganych pakietów systemowych
Nasz system korzysta z zaawansowanych narzędzi ROS 2, które należy doinstalować. Uruchom w terminalu:

```bash
sudo apt update
sudo apt install ros-humble-navigation2 \
                 ros-humble-nav2-bringup \
                 ros-humble-slam-toolbox \
                 ros-humble-m-explore \
                 ros-humble-rviz2 \
                 ros-humble-teleop-twist-keyboard \
                 python3-colcon-common-extensions
```
### Krok 3: Budowa środowiska roboczego oraz pobranie wymaganych plików

```bash
# 1. Utworzenie struktury folderów
mkdir -p ~/ros2_ws/src
cd ~/ros2_ws/src

# 2. Pobranie kodu z GitHuba
git clone https://github.com/matrix1798/robot_sofware.git

```

### Krok 4: Konfiguracja sieci:
Aby Twój PC (Panel Sterowania) mógł bezkolizyjnie komunikować się z robotem (Jetsonem), oba urządzenia muszą pracować w tej samej domenie ROS. W tym projekcie używamy ID równego 30.

```bash
source /opt/ros/humble/setup.bash
export ROS_DOMAIN_ID=30
```

### Krok 5: Uruchomienie systemu
Gdy wszystko jest już zainstalowane i zbudowane, uruchomienie Panelu Sterowania sprowadza się do jednej komendy.

```bash
python3 ~/ros2_ws/src/robot_software/control_panel.py
```

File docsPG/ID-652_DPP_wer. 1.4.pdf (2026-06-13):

SZP{akronim projektu} | Dokumentacja procesu projektowania | Projekt grupowy, WETI PG
PG_WETI_DPP_wer._1.00 | 1 / 13 | Data 13.06.2026 14:56:41

### Dokumentacja projektu grupowego

# Dokumentacja procesu projektowania

Wydział Elektroniki, Telekomunikacji i Informatyki

Politechnika Gdańska

{wersja dokumentu wzorcowego: wersja 1/2025}

Nazwa i akronim projektu: Dron kołowy do autonomicznego mapowania terenu | Zleceniodawca: Zakład Automatyki i Urządzeń Pomiarowych AREX Sp. z o.o.
Numer zlecenia: ID-656 | Kierownik projektu: Adam Błażejewski | Opiekun projektu: dr hab. inż. Bogdan Pankiewicz
Nazwa dokumentu/akronim: Dokumentacja procesu projektowania – DPP | Nr wersji: 1.3
| Data pierwszego sporządzenia: 29.01.2026

Odpowiedzialny za dokument:
Maciej Domeradzki

Data ostatniej aktualizacji: 11.06.2026

Studia I stopnia, inżynierskie
Semestr realizacji Projektu grupowego: 1 i 2

Historia zmian

Wersja | Opis modyfikacji | Rozdział / strona | Autor modyfikacji | Data
0.5 | Wstępne wersja dokumentu | calość | Mateusz Kuczerowski | 29.01.2026
0.6 | Poprawki i formatowanie | całość | Adam Błażejewski | 30.01.2026
1.0 | Aktualizacja dokumentu przed zakończeniem projektu | całość | Maciej Domeradzki | 02.06.2026
1.1 | Aktualizacja spotkań, formatowanie | sekcja 9 | Adam Błażejewski | 05.06.2026
1.2 | Dodanie załączników | Sekcja 10 | Adam Błażejewski | 06.06.2026
1.3 | Uzupełnienie spisu treści | Spis treści | Maciej Domeradzki | 11.06.2026

PG_WETI_DPP_wer._1.00 | 2 / 13 | Data 13.06.2026 14:56:41

## Spis treści

1 | Wprowadzenie - o dokumencie | 3
1.1 | Cel dokumentu | 3
1.2 | Odbiorcy | 3
1.3 | Terminologia | 3
2 | Cel i założenia projektu | 3
2.1 | Cel projektu | 3
2.2 | Założenia projektu | 3
2.2.1 | Tytuł podpunktu | 3
3 | Organizacja projektu | 3
3.1 | Zespół projektowy | 3
3.2 | Nadzór nad projektem | 4
3.3 | Infrastruktura komunikacyjna | 4
3.4 | Zarządzanie jakością w projekcie | 4
4 | Analiza ryzyka i zarządzanie ryzykiem w projekcie | 4
5 | Harmonogram prac zespołu projektowego | 5
5.1 | Opis etapów wytwarzania (prowadzenia projektu) | 5
5.1.1 | Etap A (nazwa etapu) | 5
5.1.2 | Etap B (nazwa etapu) | 5
6 | Planowany podział zadań i ról w projekcie w zespole projektowym | 5
6.1 | Opis zadań planowanych do realizacji ze wskazaniem osób odpowiedzialnych | 5
6.1.1 | Nazwa zadania/roli | 5
6.1.2 | Nazwa zadania/roli | 5
7 | Wymagania dla produktu i kryteria akceptacji | 5
7.1 | Ogólny opis planowanego produktu | 5
7.2 | Wymagania minimalne dla produktu | 5
7.3 | Warunki odbioru | 5
8 | Postanowienia | 6
8.1 | Postanowienia w zakresie zmian w stosunku do pierwotnego planu i zakresu prac | 6
8.2 | Inne postanowienia | 6
9 | Raport aktywności zespołu projektowego (semestr I i II) – rezultaty projektu | 6
9.1 | Spotkanie projektowe zespołu dnia ... | 6
9.2 | Spotkanie z opiekunem dnia ... | 6
9.3 | Spotkanie z klientem dnia ... | 6
10 Załączniki | 7

PG_WETI_DPP_wer._1.00 | 3 / 13 | Data 13.06.2026 14:56:41

### 1 Wprowadzenie - o dokumencie

### 1.1 Cel dokumentu

Celem dokumentu jest:
- uporządkowanie podstawowych informacji o projekcie, wykonawcach, temacie, zakresie projektu, wstępnie planowanym zakresie prac, zarządzaniu jakością itp.
- wykonanie uproszczonej analizy ryzyka
- udokumentowanie harmonogramu realizacji projektu w semestrze I i II, planowanego podziału zadań w zespole, wskazanie i opisanie zadań oraz ról osób odpowiedzialnych, a także wyspecyfikowanie wymagań dla projektu wraz z kryteriami akceptacji, nałożonymi przez opiekuna i klienta
- udokumentowanie aktywności zespołu, spotkań projektowych zespołu, spotkań z opiekunem itp.
- sporządzenie raportu semestralnego – podsumowania semestru I, w tym wskazanie wykonanych prac z podaniem ich krótkiej charakterystyki, wskazanie rozbieżności wykonywanych prac w stosunku do planowanych, podsumowanie prac z wykazaniem pracy zespołowej, krótkie wskazanie planów na II semestr oraz wyspecyfikowanie listy dokumentów, wytworzonych w projekcie (wersji końcowych), które zostały umieszczone i zatwierdzone przez opiekuna w serwisie SPG.
- sporządzenie raportu końcowego – podsumowania całości projektu, czyli semestru II i I, zebranie istotnych informacji dotyczących całości zrealizowanego projektu w jednym miejscu i zaprezentowanie ich w przejrzysty sposób.

### 1.2 Odbiorcy

Głównymi adresatami dokumentu są:
- Opiekun projektu: dr hab. Inż. Bogdan Pankiewicz oceniający zgodność projektu z założeniami.
- Zespół projektowy: Dokument stanowi bazę wiedzy technicznej niezbędną do dalszego rozwoju i serwisowania robota.

### 1.3 Terminologia

Lista użytych skrótów językowych wykorzystanych w dokumentacji projektu:
- MCU (Microcontroller Unit): Mikrokontroler sterujący niskopoziomowy, w projekcie STM32.
- ROS (Robot Operating System): Otwarto-źródłowy zestaw bibliotek i narzędzi do tworzenia oprogramowania dla robotów.
- LIDAR (Light Detection and Ranging): Metoda pomiaru odległości poprzez oświetlanie celu światłem laserowym; w dokumencie odnosi się do skanera laserowego 2D.
- IMU (Inertial Measurement Unit): Jednostka inercyjna integrująca akcelerometr i żyroskop.
- SLAM (Simultaneous Localization and Mapping): Algorytm jednoczesnego lokalizowania robota i budowania mapy otoczenia.
- PWM (Pulse-Width Modulation): Modulacja szerokości impulsu, wykorzystywana do sterowania mocą silników.
- UART (Universal Asynchronous Receiver-Transmitter): Interfejs komunikacji szeregowej.

### 2 Cel i założenia projektu

{Zakres projektu, główne założenia, główne wymagania, elementy składowe produktu, wstępnie planowany zakres prac, inne wg uznania opiekuna)

### 2.1 Cel projektu

Celem projektu jest zaprojektowanie, budowa oraz oprogramowanie autonomicznego robota mobilnego o napędzie kołowym. Projekt obejmuje integrację dwóch warstw sterowania: niskopoziomowej (opartej na mikrokontrolerze STM32) oraz wysokopoziomowej (opartej na komputerze Nvidia Jetson Nano). Zakres prac dotyczy zarówno warstwy sprzętowej (elektronika, mechanika, druk 3D), jak i programistycznej (algorytmy sterowania, system ROS, przetwarzanie danych z LIDAR-u, mapowanie SLAM).

### 2.2 Założenia projektu

- Modularność sterowania: Rozdział zadań na system czasu rzeczywistego (STM32 – sterowanie silnikami) oraz jednostkę obliczeniową (Jetson Nano – analiza otoczenia i decyzje nawigacyjne).

PG_WETI_DPP_wer._1.00 | 4 / 13 | Data 13.06.2026 14:56:41
- Środowisko operacyjne: Wykorzystanie Robot Operating System (ROS) jako szkieletu programistycznego do zarządzania węzłami, komunikacją i sensorami.
- Autonomia: Zdolność robota do samodzielnego mapowania przestrzeni oraz lokalizacji w niej (algorytmy SLAM).
- Hybrydowe sterowanie: Możliwość pracy w trybie autonomicznym oraz przejęcia kontroli manualnej za pomocą dedykowanego kontrolera.

### 3 Organizacja projektu

### 3.1 Zespół projektowy

Tabela 3.1. Członkowie zespołu projektowego

Lp. | Imię i nazwisko członka zespołu | Rola w projekcie | E-mail kontaktowy
1 | Adam Błażejewski | Lider zespołu | s198344@student.pg.edu.pl
2 | Maciej Domeradzki | Programista-elektronik | s197818@student.pg.edu.pl
3 | Krzysztof Toczyński | Programista-elektronik | s197986@student.pg.edu.pl
4 | Mateusz Kuczerowski | Programista-robotyk | s197900@student.pg.edu.pl

### 3.2 Nadzór nad projektem

Tabela 3.2. Osoby pełniące nadzór nad projektem

Nazwa katedry | Katedra Systemów Mikroelektronicznych
Opiekun | Prof. Bogdan Pankiewicz | e-mail: bogdan.pankiewicz@pg.edu.pl
Klient | Zakład Automatyki i Urządzeń Pomiarowych AREX Sp. z o.o. | e-mail: biuro@arex.pl
Koordynator katedralny | dr hab. inż. Jacek Jakusz | e-mail: jacjakus@pg.edu.pl
Koordynator wydziałowy | dr inż. Sławomir Gajewski | e-mail: slawomir.gajewski@eti.pg.edu.pl

### 3.3 Infrastruktura komunikacyjna

Współpraca z opiekunem projektu opiera się na elastycznym harmonogramie spotkań konsultacyjnych, ustalanych drogą mailową z inicjatywy opiekuna, w celu weryfikacji kluczowych etapów prac. Podstawowym narzędziem monitorowania postępów jest systematyczna korespondencja elektroniczna – zespół przesyła cotygodniowe raporty mailowe, zawierające szczegółowe zestawienie zadań zrealizowanych w minionym tygodniu. Model ten zapewnia opiekunowi stały wgląd w status projektu bez konieczności organizowania częstych spotkań administracyjnych.

W relacji z klientem zewnętrznym współpraca koncentruje się na pozyskaniu niezbędnych zasobów oraz wsparciu technicznym. Rola klienta obejmuje zapewnienie środków finansowych na zakup elementów projektowych, natomiast bieżące wsparcie merytoryczne realizowane jest poprzez kontakt z dedykowanym mentorem z ramienia firmy. Za koordynację przepływu informacji na linii zespół–klient oraz zespół–opiekun odpowiedzialny jest wyznaczony lider zespołu, który dba o spójność przekazywanych komunikatów i reprezentuje grupę na zewnątrz.

Organizacja pracy wewnątrz zespołu opiera się na modelu hybrydowym. Komunikacja bieżąca i szybka wymiana informacji realizowane są zdalnie za pośrednictwem komunikatorów internetowych (Messenger, Discord) oraz telefonicznie. Prace montażowe, testy oraz integracja podzespołów odbywają się podczas regularnych spotkań stacjonarnych w laboratorium udostępnionym przez opiekuna lub w przestrzeni warsztatowej Protolab. W celu zapewnienia bezpieczeństwa danych i porządku w

PG_WETI_DPP_wer._1.00 | 5 / 13 | Data 13.06.2026 14:56:41

dokumentacji, utworzono centralne repozytorium w serwisie GitHub. Platforma ta służy do wersjonowania kodu źródłowego, przechowywania dokumentacji technicznej oraz archiwizacji całego projektu, co umożliwia wszystkim członkom zespołu równoczesną pracę na aktualnych plikach.

### 3.4 Zarządzanie jakością w projekcie

Nadzór nad jakością powstającej dokumentacji projektowej sprawuje bezpośrednio lider zespołu. Jego rola polega na ostatecznej weryfikacji wszystkich wytworzonych materiałów pod kątem spójności, kompletności oraz zgodności z wymogami formalnymi przed ich oficjalnym udostępnieniem opiekunowi lub archiwizacją w systemie kontroli wersji. Taki model centralizacji kontroli pozwala na utrzymanie wysokiego standardu raportowania i eliminuje błędy redakcyjne oraz merytoryczne na etapie scalania prac poszczególnych członków grupy.

Weryfikacja poprawności wykonanych zadań technicznych oraz implementacyjnych realizowana jest w modelu zespołowym (peer review). Każdy ukończony etap prac, czy to fragment kodu, czy moduł sprzętowy, poddawany jest analizie i sprawdzeniu przez pozostałych członków zespołu. Podejście to pozwala na bieżące wykrywanie nieprawidłowości oraz optymalizację rozwiązań dzięki wymianie spostrzeżeń wewnątrz grupy. Dodatkowo, poprawność przyjętych założeń inżynierskich jest stale konfrontowana z dostępną literaturą fachową i notami katalogowymi, co stanowi punkt odniesienia dla uzyskanych wyników i zapewnia zgodność projektu ze sztuką inżynierską.

Istotnym filarem kontroli jakości oraz weryfikacji spełnienia oczekiwań klienta jest ścisła współpraca z mentorem technicznym, wydelegowanym przez firmę partnerską. Pełni on funkcję doradczą oraz kontrolną, konsultując zasadność planowanych rozwiązań (proof of concept) oraz sugerując optymalne ścieżki realizacji poszczególnych funkcjonalności. Regularne konsultacje z ekspertem z branży pozwalają na bieżącą walidację kierunku rozwoju projektu, upewniając zespół, że przyjęta metodyka jest efektywna, a finalny produkt będzie zgodny z wymaganiami rynkowymi i oczekiwaniami sponsora projektu.

### 4 Analiza ryzyka i zarządzanie ryzykiem w projekcie

Tabela 4.1. Analiza ryzyka

Lp. | Nazwa ryzyka | Ocena prawdopodobieństwa wystąpienia | Opis potencjalnych skutków | Sposoby rozwiązywania problemów
1. Wyjazd członka zespołu na | program Erasmus+ | 50% | Brak możliwości pracy stacjonarnej, utrudniona komunikacja i realizacja zadań hardware’owych | Wytyczenie zadań możliwych do realizacji zdalnej
2. | Uszkodzenie komponentów | 40% | Dodatkowe, niepotrzebne koszty | Wykonywanie symulacji
3. | Opóźnienie w zakupach | 90% | Wstrzymanie prac | Korzystanie z tanich, łatwo dostępnych elementów do prototypowania
4. | Brak wystarczającej wiedzy | 90% | Wydłużony czas rozwiązywania danego problemu | Wsparcie merytoryczne opiekuna
5. | Projekt zbyt ciężki do realizacji | 40% | Brak motywacji do działania | Wykonanie niezbędnych założeń w pierwszej kolejności
6. | Zdarzenia losowe np. choroba | 65% | Zmniejszenie, chwilowe lub na stałe, liczby członków zespołu | Dokumentacja pracy na bieżąco

### 5 Harmonogram prac zespołu projektowego

Główne etapy | Wykonawcy | Początek | Koniec
Etap A: Budowa platformy i implementacja sterowania niskopoziomowego (STM32) | Adam Błażejewski, Maciej Domeradzki | 10.11.2025 | 21.01.2026
Etap B: Konfiguracja systemu ROS2, sensoryki i komunikacji | Adam Błażejewski, Maciej Domeradzki Mateusz Kuczerowski, Krzysztof Toczyński | 10.11.2025 | 21.01.2026
Etap C: Stworzenie płytki custom PCB w celu uporządkowania organizacji komponentów na robocie | Adam Błażejewski Mateusz Kuczerowski | 31.03.2026 | 21.05.2026
Etap D: Zaprojektowanie i wydrukowanie platformy robota | Adam Błażejewski, Maciej Domeradzki | 01.04.2026 | 26.05.2026

PG_WETI_DPP_wer._1.00 | 6 / 13 | Data 13.06.2026 14:56:41
oraz zakup elementów wykonawczych (silniki, enkodery, koła) w celu przejścia z wersji prototypowej do docelowej konstrukcji robota | Mateusz Kuczerowski, Krzysztof Toczyński
Etap E: Integracja systemu oraz implementacja algorytmów autonomicznej jazdy i ich walidacja w środowisku symulacyjnym Gazebo | Adam Błażejewski, Maciej Domeradzki Mateusz Kuczerowski, Krzysztof Toczyński | 01.03.2026 | 01.06.2026
Etap F: Implementacja przygotowanych i przetestowanych w punkcie E algorytmów na robota oraz poprawki i strojenie w celu zapewnienia poprawnego działania | Adam Błażejewski, Maciej Domeradzki Mateusz Kuczerowski, Krzysztof Toczyński | 01.06.2026 | 09.06.2026

Opis etapów wytwarzania (prowadzenia projektu)

## 5.1 Opis etapów wytwarzania (prowadzenia projektu)

Poniżej przedstawiono szczegółowy zakres prac dla poszczególnych etapów realizowanych w bieżącym semestrze, prowadzących do uzyskania funkcjonalności podstawowej robota.

### 5.1.1 Etap A: Budowa platformy i implementacja sterowania niskopoziomowego

W tym etapie prace koncentrują się na warstwie fizycznej (hardware) oraz oprogramowaniu układowym (firmware). Celem jest przygotowanie bazy mechanicznej i elektronicznej zdolnej do ruchu.

- Cele: Stworzenie w pełni zmontowanej platformy jezdnej oraz zaprogramowanie mikrokontrolera do obsługi peryferiów.
- Produkty:
- Zmontowana mechanicznie platforma z silnikami i elektroniką.
- Kod źródłowy dla STM32 (sterowniki silników, obsługa czujników).
- Główne zadania:
- Integracja wszystkich komponentów sprzętowych w jedną platformę (montaż mechaniczny, lutowanie).
- Opracowanie oprogramowania dla mikrokontrolera STM32 do sterowania napędem (PWM, obsługa enkoderów).
- Opracowanie oprogramowania STM32 do obsługi podstawowych czujników pokładowych (np. IMU).
- Kryteria akceptacji:
- Platforma jest stabilna mechanicznie.
- Mikrokontroler poprawnie steruje prędkością i kierunkiem obrotu silników.
- Możliwy jest odczyt danych z czujników podłączonych do STM32.

### 5.1.2 Etap B: Konfiguracja systemu ROS2, sensoryki i komunikacji

Etap ten obejmuje uruchomienie komputer głównego robota oraz zestawienie połączeń między warstwami systemu. Kluczowym elementem jest uruchomienie skanera otoczenia.

PG_WETI_DPP_wer._1.00 | 7 / 13 | Data 13.06.2026 14:56:41
- Cele: Ustanowienie stabilnej wymiany danych między komputerem nadrzędnym a mikrokontrolerem oraz uruchomienie systemu percepcji.
- Produkty:
- Skonfigurowane środowisko ROS2 na Jetson Nano.
- Działający most komunikacyjny (bridge) Jetson ↔ STM32.
- Węzeł ROS publikujący dane z LiDARu.
- Główne zadania:
- Konfiguracja komunikacji między STM32 a środowiskiem ROS2 (definiowanie ramek danych/protokołu).
- Fizyczna i programowa konfiguracja połączenia Jetson Nano ↔ mikrokontroler (np. UART/USB).
- Integracja i uruchomienie LiDARu (instalacja sterowników, odbiór i wstępne przetwarzanie chmury punktów).
- Kryteria akceptacji:
- Komendy wysłane z Jetson Nano powodują reakcję silników (sterowanych przez STM32).
- Dane z LiDARu są widoczne w narzędziach wizualizacyjnych ROS (np. RViz).
- Transmisja danych telemetrycznych odbywa się bez błędów i opóźnień krytycznych.

### 5.1.3 Etap C: Stworzenie płytki custom PCB

Etap ten obejmuje zaprojektowanie zgodnie z wymaganiam projektu, konsultacje ze specjalistami w dziedzinie oraz przesłanie schematu do produkcji płytki custom PCB

- Cele: Stworzenie płytki PCB, zawierającej mikrokontroler STM32L476RGT6, układ czujników LSM6DSV16XTR, oraz wszystkie niezbędne interfejsy do podłączenia pozostałych komponentów (sterownik DRV8833, zasilanie, enkodery, Nvidia Jetson)
- Produkty:
- Działający produkt gotowy do zamontowania z funkcjonalnościami opisanymi powyżej
- Główne zadania:
- Projekt układu oraz przygotowanie schematu
- Konsultacja i weryfikacja sporządzonego projektu przez specjalistę
- Zlecenie produkcji
- Odbiór produktu, kontrola jakości wykonania oraz integracja w systemie
- Kryteria akceptacji:
- W pełni funkcjonalny system umożliwiający programowanie mikrokontrolera stm32 oraz poprawną jego komunikację z pozostałymi komponentami
- Kontrola jakości za pomocą multimetru i diód kontrolnych

### 5.1.4 Etap D: Zaprojektowanie i wydrukowanie platformy robota oraz zakup elementów wykonawczych

Przejście z wersji prototypowej wykorzystywanej w początkowych etapach (tania platforma zamówiona z internetu) na wersję docelową z komponentami wyższej jakości umożliwiającą precyzyjne sterowanie

- Cele: Zakup komponentów (silniki, koła i enkodery) firmy pololu oraz zamodelowanie platformy przystosowanej do montażu wszystkich komponentów i wydrukowanie jej za pomocą technologii druku 3d.
- Produkty:
- Zmontowana platforma z silnikami, enloderami i kołami pozwalająca na bezpieczne zamocowanie wszystkich komponentów oraz na precyzyjne sterowanie robotem
- Główne zadania:

PG_WETI_DPP_wer._1.00 | 8 / 13 | Data 13.06.2026 14:56:41
- Zakup elementów wykonawczych oraz zaprojektowanie rozłożenia komponentów na obu piętrach dwupoziomowej platformy
- Przygotowanie modelu 3d platformy
- Druk 3d, walidacja poprawności, poprawki i ponowny druk.
- Kryteria akceptacji:
- Stabilna mechanicznie platforma umożliwiająca precyzyjne sterowanie, brak luzów na elementach wykonawczych oraz możliwość bezpiecznego zamocowania wszystkich komponentów

### 5.1.5 Etap E: Integracja systemu oraz implementacja algorytmów autonomicznej jazdy

Połączenie wszystkich elementów na robocie oraz zapewnienie poprawnej komunikacji między nimi. Opracowanie algorytmów autonomicznej jazdy i ich walidacja w środowisku symulacyjnym Gazebo

- Cele: Przygotowanie do finalnego etapu projektu, impelmentacja algorytmów autonomicznej jazdy w środowisku symulacyjnym i umożliwienie ich sprawnej implementacji na robocie
- Produkty:
- Poprawna komunikacja między komponentami (Jetson Nano, stm32, elementy wykonawcze, czujniki)
- Działające w środowisku symulacyjnym Gazebo algorytmy (A*, Dynamic Window Approach, SLAM, mapowanie terenu za pomocą czujnika LIDAR)
- Główne zadania:
- Zaprogramowanie poprawnej komunikacji między stm i komputerem jednostką nadrzędną
- Implementacja wymienionych powyżej algorytmów w języku python i testy w środowisku symulacyjnym Gazebo
- Kryteria akceptacji:
- Poprawne działanie algorytmu w środowisku symulayjnym, biorąc pod uwagę tworzenie mapy, omijanie przeszkód i szybkość obliczeń
- Poprawna komunikacja między jednostką nadrzędną i jednostką niskopoziomową bez utraty danych

### 5.1.6 Etap F: Implementacja punktu E na robota

Ostatni etap projektu skupia się na uruchomieniu przygotowanych i przetestowanych w punkcie E algorytmów autonomicznej jazdy na Robota w celu zapewnienia jego wszystkich zakładanych funkcjonalności

- Cele: Przygotowanie robota do autonomicznej jazdy w pomieszczeniu oraz preparowania mapy na podstawie danych z czujnika LIDAR
- Produkty:
- Działający algorytm SLAM (tworzenie mapy).
- Działający system nawigacji (planowanie ścieżki).
- Zintegrowany system gotowy do prezentacji.
- Główne zadania:
- Implementacja algorytmów przetwarzania danych LiDAR w celu tworzenia mapy otoczenia (SLAM).
- Implementacja na robocie, strojenie i poprawki algorytmów wyznaczania trasy i autonomicznego poruszania się robota
- Finalna integracja wszystkich komponentów w całość i testy funkcjonalne.
- Kryteria akceptacji:

PG_WETI_DPP_wer._1.00 | 9 / 13 | Data 13.06.2026 14:56:41
- Robot potrafi samodzielnie stworzyć mapę pomieszczenia na podstawie danych z LiDARu.
- Robot autonomicznie omija przeszkody
- System działa stabilnie jako całość

### 6 Planowany podział zadań i ról w projekcie w zespole projektowym

### 6.1 Opis zadań planowanych do realizacji ze wskazaniem osób odpowiedzialnych

Semestr 1:

### 6.1.1 Specjalista ds. Systemów Autonomicznych (ROS & Vision)

- Osoba/y: Krzysztof Toczyński, Mateusz Kuczerowski
- Odpowiedzialność:
- Konfiguracja systemu na Nvidia Jetson Nano.
- Integracja sterowników LIDAR-u w środowisku ROS.
- Implementacja algorytmów SLAM i nawigacji.
- Interpretacja danych pomiarowych.

### 6.1.2 Specjalista ds. Elektroniki i Systemów Wbudowanych (Embedded)

- Osoba/y: Adam Błażejewski, Maciej Domeradzki
- Odpowiedzialność:
- Dobór i montaż komponentów elektronicznych.
- Programowanie mikrokontrolera STM32 (PWM, obsługa enkoderów).
- Implementacja protokołu komunikacyjnego po stronie STM32.

Semestr 2:

### 6.1.3 Specjalista ds. Systemów Autonomicznych (ROS & Vision)

- Osoba/y: Krzysztof Toczyński, Mateusz Kuczerowski
- Odpowiedzialność:
- Implementacja i testy algorytmów autonomicznej jazdy i nawigacji w środowisku symulacyjnym.
- Przeniesienie zwalidowanych w symulacji algorytmów autonomicznej jazdy na robota i zapewnienie ich poprawnego działania w rzeczywistym środowisku
- Interpretacja danych pomiarowych.

### 6.1.4 Specjalista ds. Elektroniki i Systemów Wbudowanych (Embedded)

- Osoba/y: Adam Błażejewski, Maciej Domeradzki
- Odpowiedzialność:
- Implementacja protokołu komunikacyjnego po stronie STM32.
- Zaprojektowanie płytki custom PCB z mikrokontrolerem STM32 oraz modułem LSM6DSV16X
- Zmiana silników z enkoderami w celu zwiększenia precyzji sterowania
- Zamodelowanie i wydrukowanie platformy dostosowanej pod wykorzystywane komponenty (druk 3d)

PG_WETI_DPP_wer._1.00 | 10 / 13 | Data 13.06.2026 14:56:41

### 7 Wymagania dla produktu i kryteria akceptacji

### 7.1 Ogólny opis planowanego produktu

Efektem końcowym projektu ma być dron lądowy zdolny do autonomicznej jazdy (jak i za pomocą sterowania ręcznego) i mapowania otoczenia.

### 7.2 Wymagania minimalne dla produktu

### 7.2.1 Wymagania jakościowe

- Zdolność do poruszania się po płaskim terenie
- Prawidłowe odczytywanie danych z LiDAR w promieniu 360°
- Generowanie mapy terenu 2D za pomocą SLAM
- Możliwość pracy na baterii co najmniej 20 minut

### 7.2.2 Metody zbadania wymagań minimalnych i ich weryfikacja

- Wizualne określenie jazdy wzdłuż linii, pomiar zadanego oraz rzeczywistego kąta obrotu
- Odczytanie logów z sensora LiDAR, zestawienie ich czasów wystąpienia z czasem rzeczywistym (kontrola braku opóźnień)
- Stworzenie mapy pomieszczenia zamkniętego o znanych wymiarach i porównanie z wynikami uzyskanymi za pomocą SLAM
- Pomiar czasu ciągłej pracy robota

### 7.3 Warunki odbioru

- Poprawność merytoryczna - spełnienie wymagań minimalnych dla projektu
- Dostarczenie dokumentacji projektowej
- Prezentacja efektu końcowego klientowi
- Poprawne przejście testów weryfikacyjnych

### 8 Postanowienia

### 8.1 Postanowienia w zakresie zmian w stosunku do pierwotnego planu i zakresu prac

Nie dotyczy

### 8.2 Inne postanowienia

Nie dotyczy

### 9 Raport aktywności zespołu projektowego (semestr I i II) – rezultaty projektu

### 9.1 Spotkanie projektowe zespołu dnia 26.10.2025 Uczestnicy: Cały zespół. Przeprowadzono

wstępny research literaturowy i rynkowy. Sporządzono listę niezbędnych komponentów oraz wykonano szacunkowy bilans mocy układu zasilania.

9.2 Spotkanie z opiekunem dnia 04.11.2025 Uczestnicy: Cały zespół, Opiekun. Ustalono ostateczną tematykę oraz zakres merytoryczny projektu. Omówiono wstępne założenia funkcjonalne robota.

9.3 Spotkanie z opiekunem dnia 07.11.2025 Uczestnicy: Cały zespół, Opiekun. Podjęto ostateczną decyzję o wyborze projektu. Zatwierdzono nazwę i oficjalny opis. Odebrano od opiekuna tymczasowe komponenty w celu rozpoczęcia prac wstępnych. Ustalono szczegóły dotyczące planowanego spotkania z firmą partnerską.

9.4 Spotkanie projektowe zespołu dnia 07.11.2025 Uczestnicy: Cały zespół Dokonano podziału zadań pomiędzy członków zespołu. Zapoznano się z otrzymanymi komponentami i na ich podstawie spisano wstępny kosztorys projektu.

PG_WETI_DPP_wer._1.00 | 11 / 13 | Data 13.06.2026 14:56:41

### 9.5 Spotkanie projektowe zespołu dnia 10.11.2025 Uczestnicy: Adam Błażejewski, Maciej

Domeradzki. Opracowano wstępne wersje kodów sterujących na mikrokontroler STM32. Zainstalowano i skonfigurowano środowisko ROS2 na maszynie wirtualnej w celu pierwszych testów.

9.6 Spotkanie z opiekunem dnia 14.11.2025 Uczestnicy: Cały zespół, Opiekun. Podpisano niezbędną dokumentację formalną projektu. Skontaktowano się z sekretariatem w celu ustalenia procedur finansowania zakupów.

### 9.7 Spotkanie projektowe zespołu dnia 15.11.2025 Uczestnicy: Adam Błażejewski, Krzysztof

Toczyński. Skonfigurowano środowisko Linux na stacji roboczej. Podjęto próbę instalacji natywnej wersji ROS2 oraz weryfikacji kompatybilności bibliotek.

### 9.8 Spotkanie projektowe zespołu dnia 17.11.2025 Uczestnicy: Adam Błażejewski, Krzysztof

Toczyński, Mateusz Kuczerowski. Kontynuowano prace konfiguracyjne nad ROS2 (rozwiązywanie problemów z zależnościami). Przeprowadzono testy sterownika silników przy użyciu mikrokontrolera STM32.

9.9 Spotkanie z klientem dnia 20.11.2025 Uczestnicy: Cały zespół, przedstawiciele firmy AREX. Wizyta w siedzibie firmy AREX. Zaprezentowano szczegóły projektu i omówiono kwestie finansowania oraz wsparcia merytorycznego. Zwiedzanie zaplecza technicznego firmy

### 9.10 Spotkanie projektowe zespołu dnia 23.11.2025 Uczestnicy: Adam Błażejewski, Maciej

Domeradzki. Złożono fizyczny układ testowy składający się z mikrokontrolera, czujników, sterownika i silników. Skonfigurowano napęd i rozwiązano problemy komunikacyjne ze sterownikiem.

9.11 Spotkanie z opiekunem dnia 28.11.2025 Uczestnicy: Adam Błażejewski, Krzysztof Toczyński, Opiekun. Skonsultowano wątpliwości techniczne dotyczące sterownika silników. Ustalono dalszy plan działania w zakresie doboru docelowych części zamiennych.

### 9.12 Spotkanie projektowe zespołu dnia 03.12.2025 Uczestnicy: Cały zespół. Zmontowano

mechaniczną podstawę robota. Napisano program obsługi czujników peryferyjnych. Rozpoczęto prace nad integracją i odczytem danych z LIDAR-u.

9.13 Spotkanie z klientem dnia 13.01.2026 Uczestnicy: Adam Błażejewski, Krzysztof Toczyński, przedstawiciel firmy. Spotkanie w celu odbioru zamówionych części i podzespołów ufundowanych przez firmę partnerską.

9.14 Spotkanie projektowe zespołu dnia 14.01.2026 Uczestnicy: Mateusz Kuczerowski, Krzysztof Toczyński. Zapoznano się z nowym komputerem jednopłytkowym otrzymanym od firmy. Rozpoczęto wstępną konfigurację systemu na nowej jednostce obliczeniowej.

### 9.15 Spotkanie projektowe zespołu dnia 22.01.2026 Uczestnicy: Cały zespół. Spotkanie

podsumowujące etap. Zweryfikowano postępy prac na nowym sprzęcie, omówiono stan integracji podzespołów i zaplanowano działania na okres sesji egzaminacyjnej.

### 9.16 Spotkanie z klientem w biurze na Politechnice Gdańskiej 2.03.2026 Uczestnicy: Adam

Błażejewski, Mateusz Kuczerowski. Spotkanie firmy Arex w CI task z wszystkimi grupami projektowymi. Otwarcie drugiego semestru, podsumowanie dotychczasowych prac i omówienie celów na następny etap projektu

PG_WETI_DPP_wer._1.00 | 12 / 13 | Data 13.06.2026 14:56:41

### 9.17 Spotkanie projektowe zespołu dnia 4.03.2026 Uczestnicy: Adam Błażejewski, Mateusz

Kuczerowski. Prace nad systemem ROS2

### 9.18 Spotkanie projektowe zespołu dnia 11.03.2026 Uczestnicy: Adam Błażejewski, Mateusz

Kuczerowski. Programowanie stm32

### 9.19 Spotkanie projektowe zespołu dnia 17.03.2026 Uczestnicy: Adam Błażejewski, Mateusz

Kuczerowski. Konfiguracja autostartu systemu ROS2

### 9.20 Spotkanie projektowe zespołu dnia 25.03.2026 Uczestnicy: Adam Błażejewski, Mateusz

Kuczerowski. Instalacja i konfiguracja linuxa i środowiska ros2 na laptopie do zdalnego sterowania

### 9.21 Spotkanie projektowe zespołu dnia 30.03.2026 Uczestnicy: Adam Błażejewski, Mateusz

Kuczerowski. Skonfigurowanie zdalnego połączenia ros2 na dwóch komputerach

### 9.22 Spotkanie z opiekunem oraz przedstawicielem klienta 31.03.2026 Uczestnicy: Adam

Błażejewski, Mateusz Kuczerowski, Opiekun i przedstawiciel z firmy Arex. Omówienie technicznych aspektów projektu.

### 9.23 Spotkanie projektowe zespołu dnia 1.04.2026 Uczestnicy: Adam Błażejewski, Mateusz

Kuczerowski. Zlutowanie nowych silników z enkoderami, podłączanie ich do nowej platformy, opracowanie nowego schematu podłączeń elektrycznych, praca nad sterowaniem lidarem ze zdalnego komputera

### 9.24 Spotkanie projektowe zespołu dnia 9.04.2026 Uczestnicy: Adam Błażejewski, Mateusz

Kuczerowski. Konfiguracja środowiska ros, projekt pcb

### 9.25 Spotkanie projektowe zespołu dnia 16.04.2026 Uczestnicy: Adam Błażejewski, Mateusz

Kuczerowski. Konfiguracja środowiska ros, wprowadzanie poprawek do projektu pcb

9.26 Spotkanie z przedstawicielem klienta dnia 28.04.2026 Uczestnicy: Adam Błażejewski, Mateusz Kuczerowski, Przedstawiciel Klienta. Spotkanie w pokoju koła naukowego Chip, z przedstawicielem klienta w celu konsultacji w sprawach projektowych

### 9.27 Spotkanie projektowe zespołu dnia 15.05.2026 Uczestnicy: Adam Błażejewski, Mateusz

Kuczerowski. Lutowanie płytki pcb

9.28 Spotkanie z przedstawicielem klienta dnia 18.05.2026 Uczestnicy: Adam Błażejewski, Mateusz Kuczerowski, Przedstawiciel Klienta. Spotkanie zdalne z przedstawicielem klienta w celu konsultacji w sprawach projektowych

### 9.29 Spotkanie projektowe zespołu dnia 21.05.2026 Uczestnicy: Adam Błażejewski, Mateusz

Kuczerowski. Poprawa lutowania komponetów na płytce pcb

### 9.30 Spotkanie projektowe zespołu dnia 26.05.2026 Uczestnicy: Adam Błażejewski, Mateusz

Kuczerowski. Złozenie wydrukowanych elementów i ich konfiguracja

PG_WETI_DPP_wer._1.00 | 13 / 13 | Data 13.06.2026 14:56:41

9.31 Spotkanie z opiekunem oraz przedstawicielem klienta dnia 1.06.2026 Uczestnicy: cały zespół, Opiekun i przedstawiciel z firmy Arex. Podsumowanie dotychczasowych prac, prezentacja wyników i aktualnego stanu projektu

### 9.32 Spotkanie projektowe zespołu dnia 4.06.2026 Uczestnicy: Adam Błażejewski, Mateusz

Kuczerowski. Debugowanie kodu odpowiedzialnego za wymianę informacji pomiędzy komputerem głównym a wykonawczym. Poprawa algorytmu autonomicznego mapowania.

### 9.33 Spotkanie projektowe zespołu dnia 8.06.2026 Uczestnicy: Adam Błażejewski, Mateusz

Kuczerowski. Ostateczne poprawki działania robota. Przygotowanie robota i przezentacji do katedralego zdania projektu.

9.34 Oddanie projektu dnia 9.06 Uczestnicy: Cały zespół, opiekun, komisja. Prezentacja ostatecznego produktu i obrona projektu

### 10 Załączniki

- Repozytorium projektu (https://github.com/adasbl/Projekt-Grupowy-ID-656.git)
- Oprogramowanie i instrukcja do obsługi robota (https://github.com/matrix1798/robot_sofware.git)
- Repozytorium płytki sterownika wykonawczego (https://github.com/adasbl/main-controller-pcb.git)

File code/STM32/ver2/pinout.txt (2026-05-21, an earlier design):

PINOUT

SYS debug - serial wire (PA14, PA13) + JTDO (PB3)

TIM2 - combined channels (enkonder mode)
PA0 - Enk1_OA
PA1 - Enk1_OB

TIM3 - combined channels (enkonder mode)
PA6 - Enk2_OA
PA7 - Enk2_OB

TIM4 - PWM Generation CH1-4
PC6 - Sil1_M1
PC7 - Sil1_M2
PC8 - Sil2_M1
PC9 - Sil2_M2

I2C1 - I2C
PB7 - I2C1_SDA
PB6 - I2C1_SCL

UART3 - Asynchronus
PC4 - USART3_TX
PC5 - USART3_RX

GPIO:
gpio EXTI13:
PC13 - B1
gpio output:
PC1 - D1
PC2 - D2
PC3 - D3

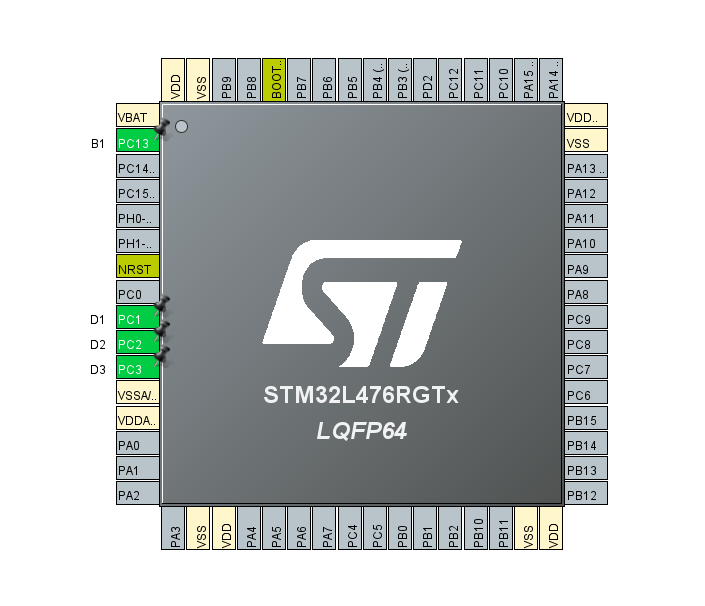
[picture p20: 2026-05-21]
code/STM32/diodeButtonTest/pinout.png

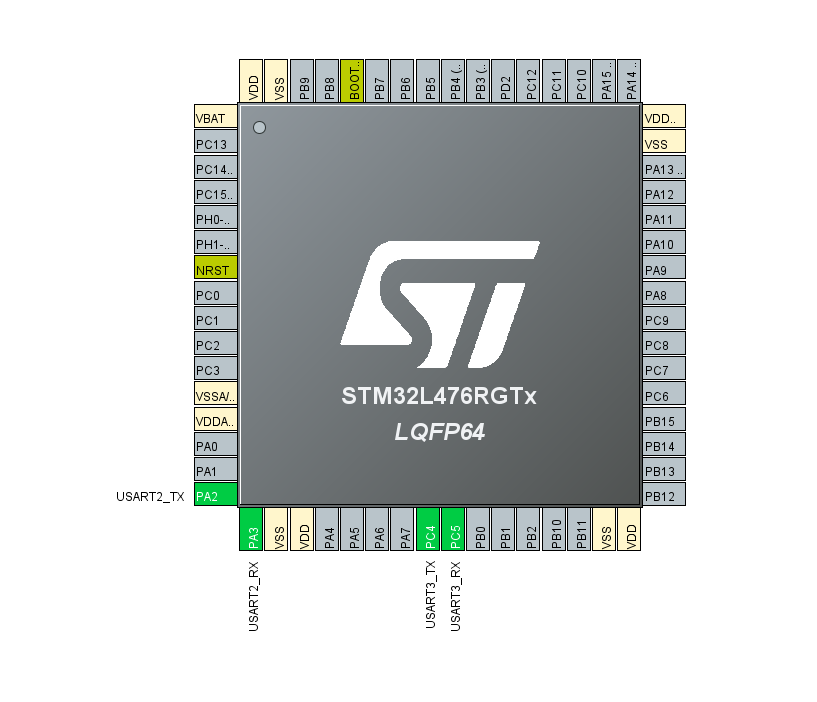
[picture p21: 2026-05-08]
code/STM32/uartTest/pinout.png

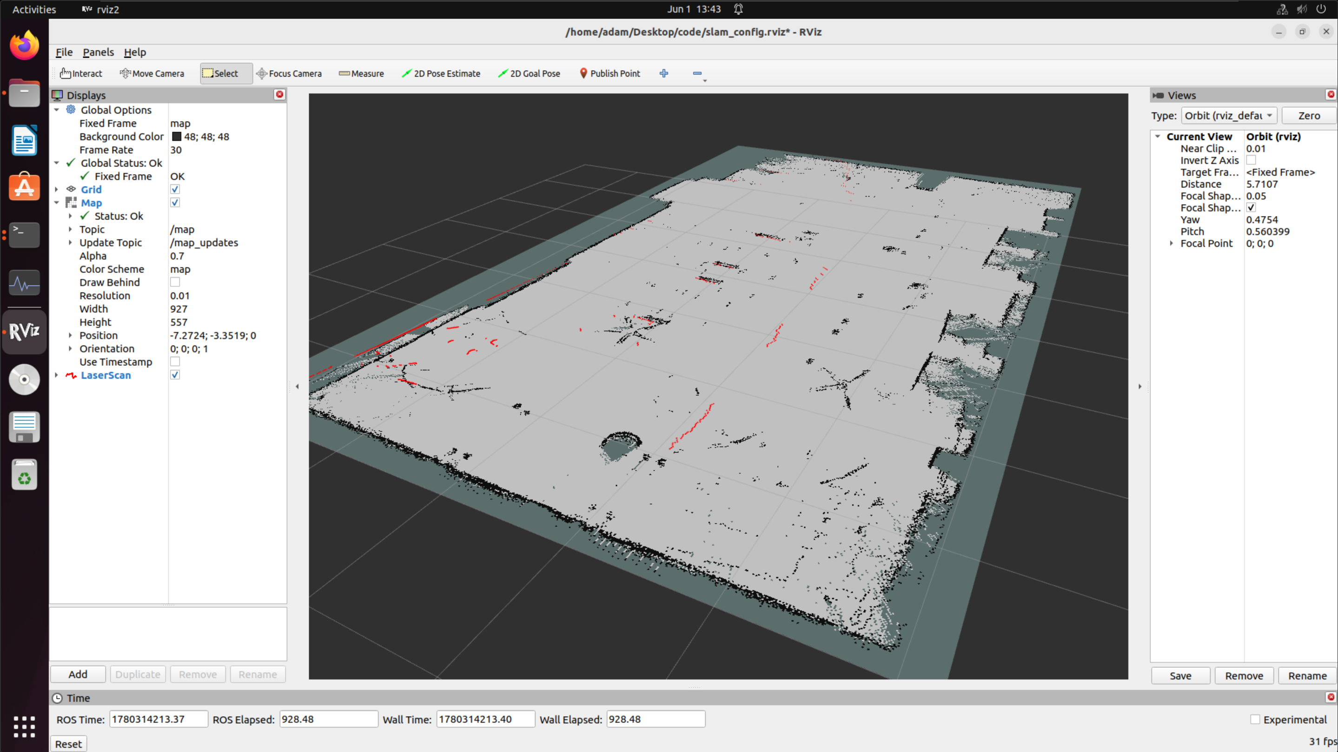
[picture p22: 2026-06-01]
img/rviz-visualization.png

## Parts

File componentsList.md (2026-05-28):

# Zestawienie komponentów projektu

## 1. Komponenty główne

### Jednostki obliczeniowe (NVIDIA Jetson / Alternatywy)
* **NVIDIA Jetson Nano Dev Kit (Waveshare)**: Dostępne na Amazon oraz Botland.
* **NVIDIA Jetson Orin Nano Super Developer Kit**: Dostępny na Nstonline.
* **Alternatywy**: Raspberry Pi 5 oraz BeagleBone® AI-64.

### Skaner laserowy (LIDAR)
* **RPLiDAR A1M8-R6 360**: Skaner laserowy 360 stopni, 12m.

### Sterowanie i zasilanie
* **Sterowniki silników**:
    * SB Pi Motor Shield SKU 08001.
    * L298N (dwukanałowy sterownik silników 12V 2A).
* **Zasilanie**:
    * Waveshare UPS Module 3S (moduł zasilacza bezprzerwowego dla Jetson Nano).
    * Wymagane złącze: XH 2.54 - 2 piny.

### Podwozie
* **Chassis Round 2WD**: 2-kołowe podwozie robota z napędem.

---

## 2. Komponenty dodatkowe

* **Karty sieciowe**: Intel 8265NGW, Intel 9260NGW, TP-LINK Archer T2U Plus.
* **Antena**: Molex 146153-1150 (Bluetooth, WiFi, ZigBee; 2,8dBi, 3,7dBi).

---

## 3. Niezbędne okablowanie

* **Kable**:
    * XH 2.54-2piny --> Jack (zasilanie Jetsona z baterii).
    * USB --> mikro USB (połączenie Jetson do lidara).

---

## 4. Propozycje do zamówienia

| Kategoria | Pozycje |
| :--- | :--- |
| **LIDAR** | RPLiDAR A1M8-R6 (Botland, Erli, Kamami) |
| **Podstawa** | Chassis Round 2WD, wersja aluminiowa, Velleman VMA500, DFRobot MiniQ |

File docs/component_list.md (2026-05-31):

# Components
| Category | Items | Links |
| :--- | :--- | :--- |
| **Computing Units** | **NVIDIA Jetson**<br> NVIDIA Jetson Nano Dev Kit (Waveshare) | [NVIDIA Jetson Nano Dev Kit](https://botland.com.pl/moduly-nvidia/21868-nvidia-jetson-nano-dev-kit-arm-cortex-a57-4x-143ghz-nvidia-maxwell-4gb-ram-16gb-emmc-waveshare-21802.html) |
| | **Microcontroller**: STM32L476RGT6<br>*(Nucleo version for debugging, target embedded board)* | [STM32L476RG Nucleo Board](https://www.st.com/en/evaluation-tools/nucleo-l476rg.html)<br>[Main controller PCB - GitHub](https://github.com/adasbl/main-controller-pcb.git) |
| **LIDAR** | **RPLiDAR A1**<br>360-degree laser scanner, 12m | [RPLiDAR A1M8-R6](https://botland.com.pl/skanery-laserowe/19625-skaner-laserowy-rplidar-a1m8-r6-360-stopni-12m-seeedstudio-114992561-5904422369248.html) |
| **Control & Power** | **DRV8833**<br>Dual-channel motor driver (H-bridge) 2.7 V - 10.8 V | [DRV8833 Driver](https://sklep.msalamon.pl/produkt/sterownik-silnika-dc-drv8833/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) |
| | **Waveshare UPS Module 3S**<br>uninterruptible power supply module for Jetson Nano | [Waveshare UPS Module 3S](https://botland.com.pl/zasilanie-nvidia/19045-zasilacz-awaryjny-ups-modul-zasilajacy-do-jetson-nano-5v-waveshare-18307-5904422366704.html) |
| | **Li-Ion Cells**<br> 18650 Li-Ion Samsung INR18650-35E 3400mAh | [Samsung 18650 Cell](https://botland.com.pl/akumulatory-li-ion/15216-ogniwo-18650-li-ion-samsung-inr18650-35e-3400mah-5904422343071.html) |
| **Platform** | **Drive Motors**<br> 298:1 MICRO METAL GEARMOTOR | [Pololu 2208 Motor](https://www.tme.eu/pl/details/pololu-2208/silniki-dc/pololu/298-1-micro-metal-gearmotor/) |
| | **Wheels**<br> POLOLU WHEEL 70X8MM | [Pololu 1425 Wheels](https://www.tme.eu/pl/details/pololu-1425/akcesoria-do-robotyki-i-rc/pololu/pololu-wheel-70x8mm-pair-black/) |
| | **Magnetic Encoders**<br> Pololu 3081 Encoders 2.7-18V | [Pololu 3081 Magnetic Encoders](https://botland.com.pl/enkodery/4884-zestaw-enkoderow-magnetycznych-do-micro-silnikow-pololu-kompatybilne-z-hpcb-27-18v-2-szt-pololu-3081-5904422309763.html) |
| | **Motor Mounts**<br> Pololu 1086 | [Pololu 1086 Mounts](https://botland.com.pl/mocowania-silnikow/25-mocowania-do-micro-silnikow-pololu-biale-2szt-pololu-1086-5904422300272.html) |
| **Communication** | **Network Card**<br> Intel 8265NGW | [Intel Dual Band Wireless-AC 8265 Specifications](https://www.intel.com/content/www/us/en/products/sku/94150/intel-dual-band-wirelessac-8265/specifications.html) |
| | **Antenna**<br> Molex 146153-1150 (Bluetooth, WiFi, ZigBee; 2.8dBi, 3.7dBi) | [Molex 146153-1150 Antenna](https://www.tme.eu/pl/details/1461531150/anteny-wifi-bluetooth/molex/146153-1150/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) |

<br><br><br>

## Changed Components

| Category / Description | Items | Links |
| :--- | :--- | :--- |
| **Chassis** | **Chassis Round 2WD**<br>2-wheel robot chassis with drive | [Chassis Round 2WD](https://botland.com.pl/podwozia-robotow/7243-chassis-round-2wd-2-kolowe-podwozie-robota-z-napedem-5904422310028.html) |
| **Driver** | **L298N**<br>dual-channel motor driver 12V 2A | [L298N Driver](https://botland.com.pl/sterowniki-silnikow-moduly/3164-l298n-dwukanalowy-sterownik-silnikow-modul-12v-2a-5904422359317.html) |

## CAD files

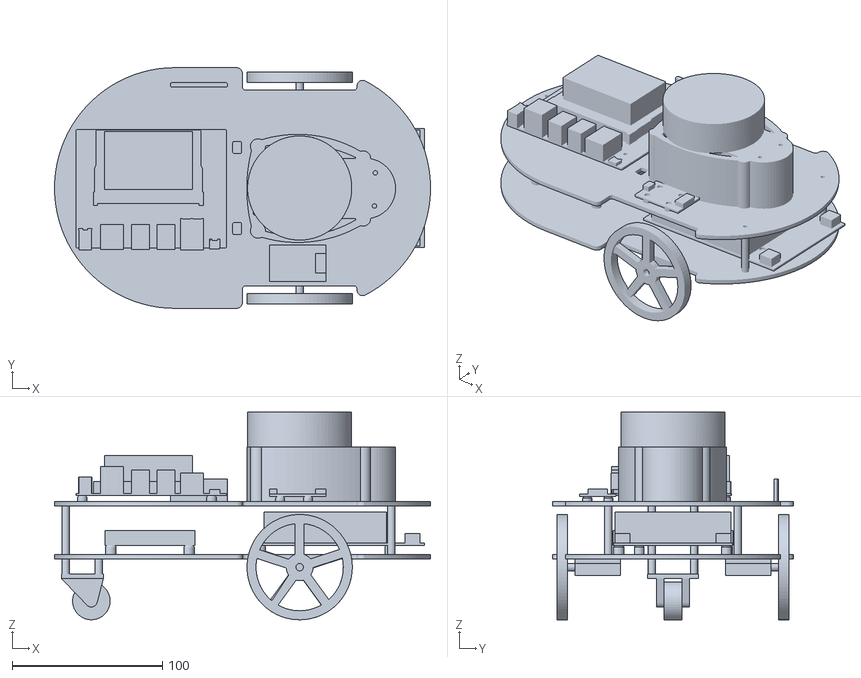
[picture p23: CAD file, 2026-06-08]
3Dmodels/assembly/robot-assembly-simplified.stl
250.0 x 160.0 x 138.0

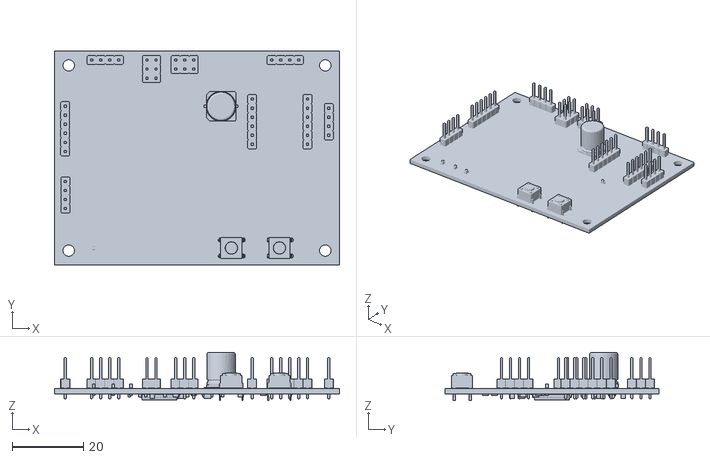
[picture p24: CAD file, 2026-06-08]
3Dmodels/components/main-controller.stl
80.0 x 60.0 x 13.5

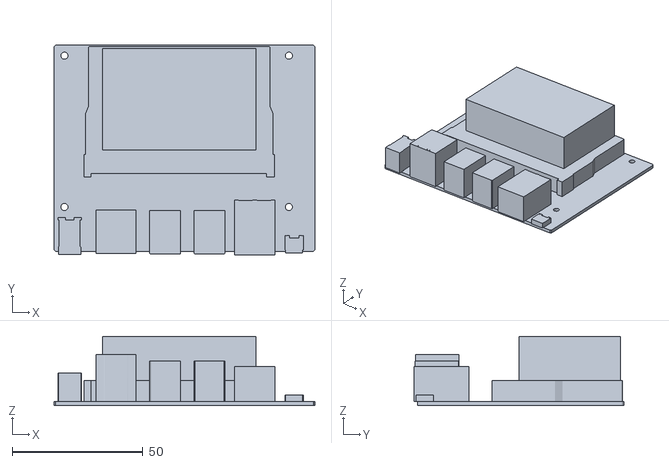
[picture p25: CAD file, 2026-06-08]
3Dmodels/components/jetson-nano-simplyfied.stl
100.0 x 80.3 x 26.6

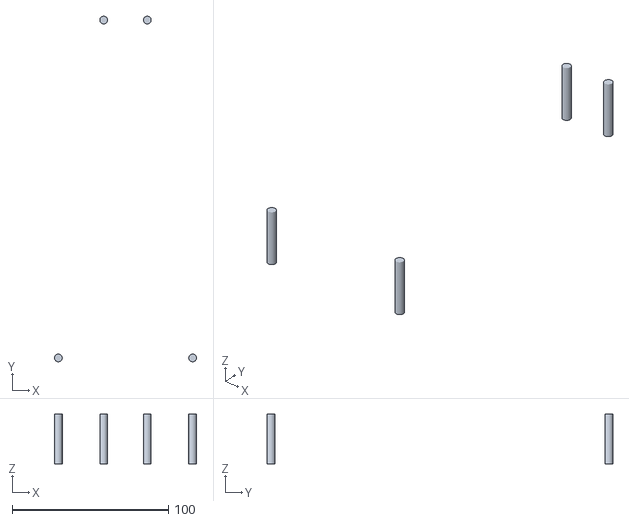
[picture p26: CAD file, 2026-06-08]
3Dmodels/platform/stands.stl
91.0 x 221.5 x 32.0

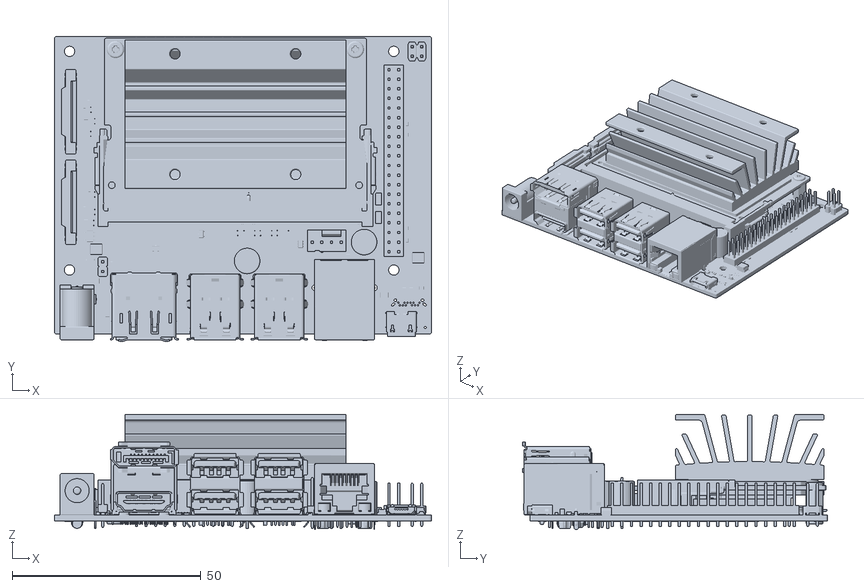
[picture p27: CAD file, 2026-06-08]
3Dmodels/components/jetson-nano-dev-kit_3D_b01.stl
100.0 x 81.0 x 30.5

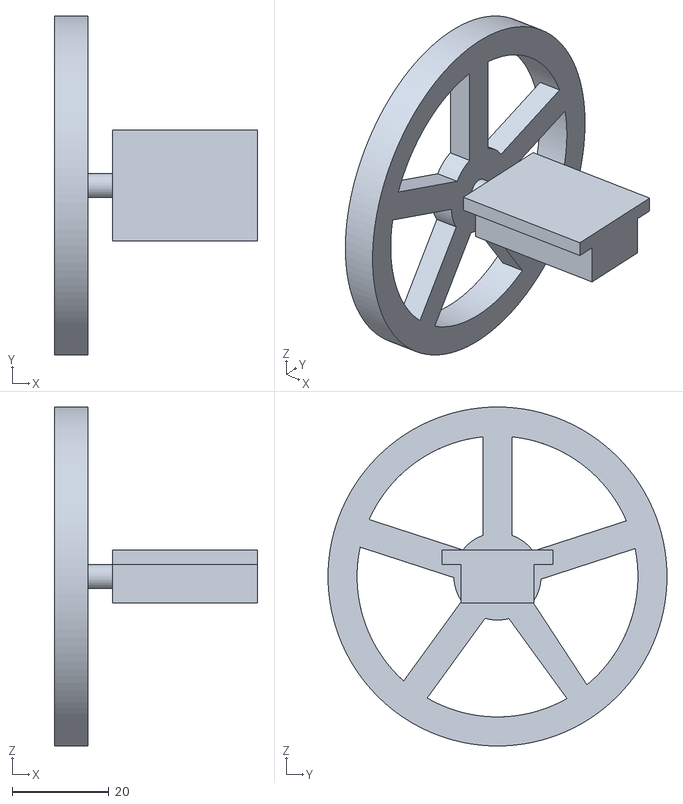
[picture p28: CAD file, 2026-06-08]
3Dmodels/platform/wheels-engine.stl
42.0 x 70.0 x 70.0

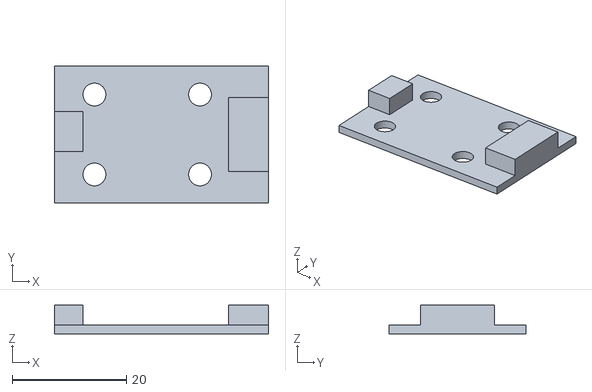
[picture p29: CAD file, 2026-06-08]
3Dmodels/components/usb-adapter.stl
37.5 x 24.0 x 5.00

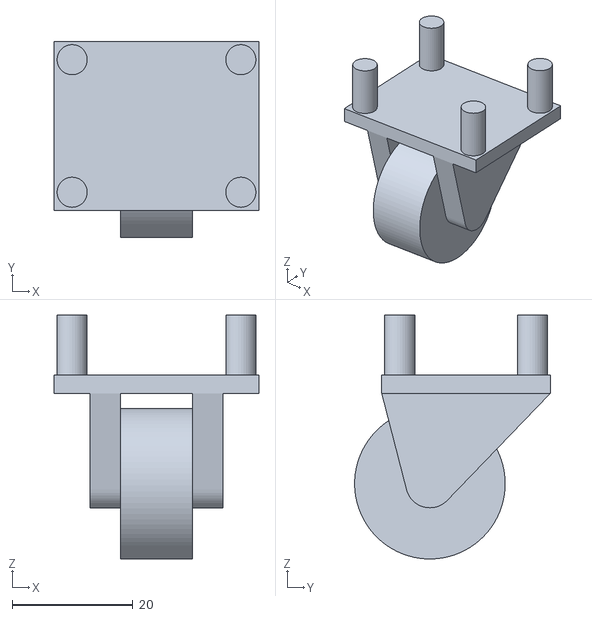
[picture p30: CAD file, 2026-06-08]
3Dmodels/platform/assist-wheel.stl
34.0 x 32.5 x 40.5

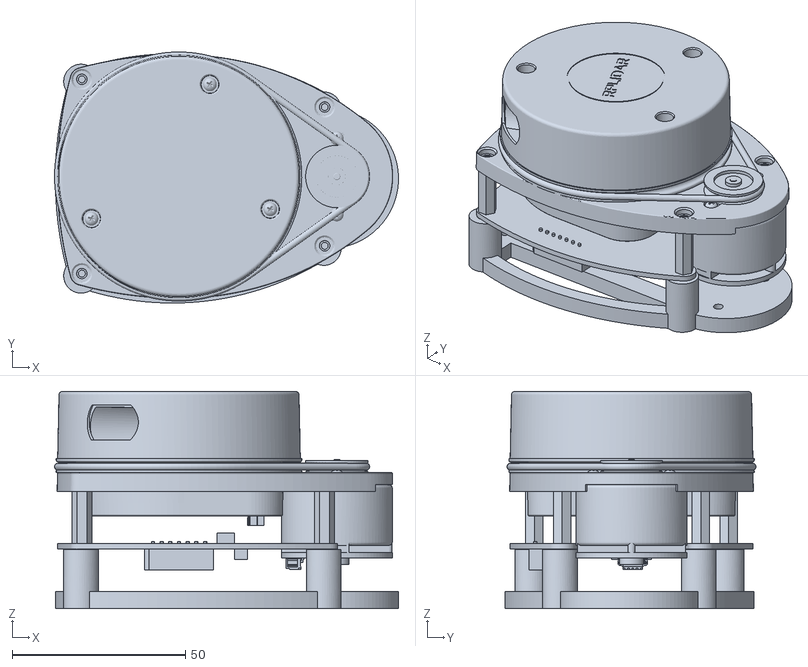
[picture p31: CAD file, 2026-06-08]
3Dmodels/components/rp-lidar.stl
99.2 x 72.4 x 62.6

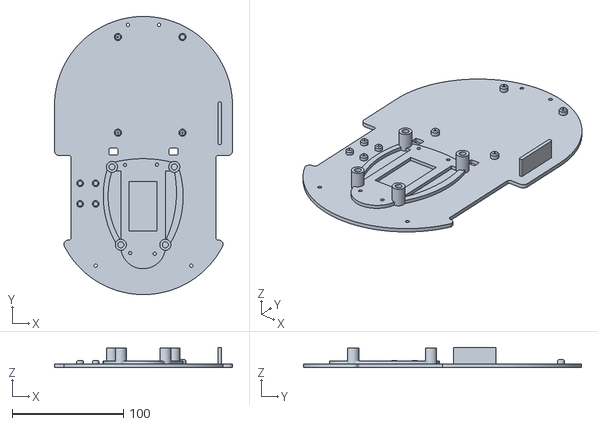
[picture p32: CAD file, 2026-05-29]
3Dmodels/platform/up-platform.stl
160.0 x 250.0 x 18.0

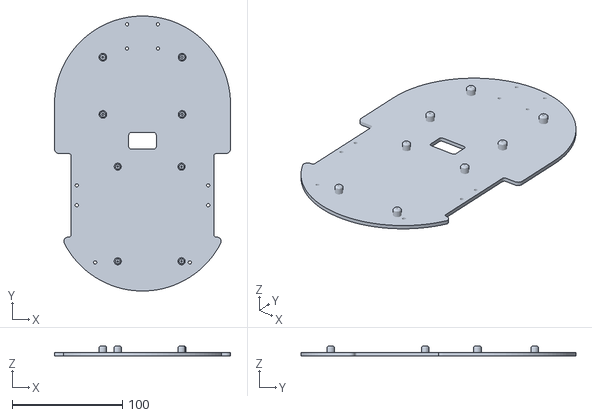
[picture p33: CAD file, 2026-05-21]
3Dmodels/platform/low-platform.stl
160.0 x 250.0 x 9.00

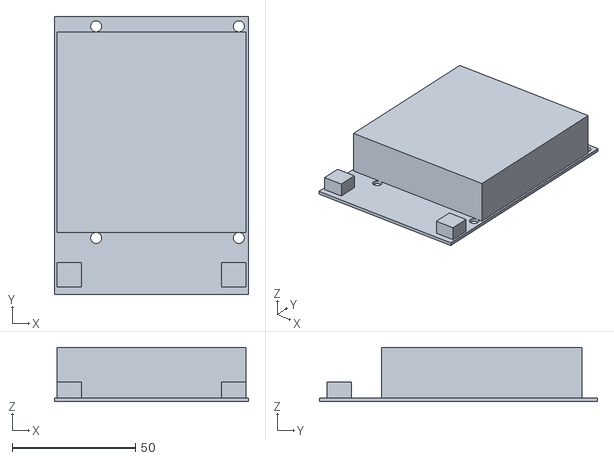
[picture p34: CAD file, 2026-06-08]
3Dmodels/components/battery-pack.stl
79.0 x 113.0 x 22.0

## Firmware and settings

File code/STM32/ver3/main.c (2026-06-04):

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

/* Includes ------------------------------------------------------------------*/
#include "main.h"
#include "tim.h"
#include "usart.h"
#include "gpio.h"

/* USER CODE BEGIN Includes */
#include <stdio.h>
#include <string.h> // Do memcpy
// #include "iks4a1_motion_sensors.h" // Odkomentuj jesli faktycznie uzywasz
// #include "custom_bus.h"
/* USER CODE END Includes */

/* USER CODE BEGIN PTD */

/*
 * Struktura ramki z ROS:
 * [0]   : 0xAA (start)
 * [1-4] : float linear velocity (m/s)
 * [5-8] : float angular velocity (rad/s)
 * [9]   : 0x55 (stop)
 */
#pragma pack(push, 1)
typedef struct {
    uint8_t header;
    float v_lin;
    float v_ang;
    uint8_t footer;
} TelemetryFrame_t;
#pragma pack(pop)

/* USER CODE END PTD */

/* USER CODE BEGIN PD */

// ZMIENNE KINEMATYCZNE - DO DOSTOSOWANIA DO FIZYCZNEGO ROBOTA
#define WHEEL_BASE_M       0.148f      // Rozstaw kół w metrach (d)
#define TICKS_PER_METER    16262.0f   // Ile impulsów enkodera odpowiada 1 metrowi
#define DT_S               0.025f    // Czas pętli sterowania (25 ms)
// #define TIMEOUT_MS         500       // Zatrzymanie silników po 500 ms bez komend z UART

/* USER CODE END PD */


/* USER CODE BEGIN PV */

// Zmienne UART
uint8_t rx_buffer[10];
uint8_t rx_index = 0;
volatile uint8_t new_data_flag = 0;
TelemetryFrame_t rxFrame;
uint32_t last_cmd_time = 0;

// Zmienne sterowania
int target_speed_L = 0;
int target_speed_R = 0;

float Kp = 12.0;
float Ki = 0.5;

float calka_L = 0;
float calka_R = 0;
volatile float uchyb_L;
volatile float uchyb_R;

int16_t prev_licznik1 = 0;
int16_t prev_licznik2 = 0;
int32_t prev_czas = 0;

int deadband = 400;
float antyWindUp = 2000;

volatile int16_t current_cnt1, current_cnt2;
volatile int16_t speed1, speed2;

volatile int in1 = 0, in2 = 0, in3 = 0, in4 = 0;

/* USER CODE END PV */

void SystemClock_Config(void);

/* USER CODE BEGIN PFP */
void pwm(int s1_m1, int s1_m2, int s2_m1, int s2_m2);
int clamp(int value, int min, int max);
/* USER CODE END PFP */

/* USER CODE BEGIN 0 */

void pwm(int s1_m1, int s1_m2, int s2_m1, int s2_m2) {
    __HAL_TIM_SET_COMPARE(&htim8, TIM_CHANNEL_1, s1_m1);
    __HAL_TIM_SET_COMPARE(&htim8, TIM_CHANNEL_2, s1_m2);
    __HAL_TIM_SET_COMPARE(&htim8, TIM_CHANNEL_3, s2_m1);
    __HAL_TIM_SET_COMPARE(&htim8, TIM_CHANNEL_4, s2_m2);
}

int clamp(int value, int min, int max) {
    if (value < min) return min;
    if (value > max) return max;
    return value;
}

/* USER CODE END 0 */

int main(void)
{
  HAL_Init();
  SystemClock_Config();

  MX_GPIO_Init();
  MX_TIM2_Init();
  MX_TIM3_Init();
  MX_TIM8_Init();
  MX_USART3_UART_Init();

  /* USER CODE BEGIN 2 */

  // Konfiguracja TIM8
  __HAL_TIM_SET_AUTORELOAD(&htim8, 999);
  HAL_TIM_PWM_Start(&htim8, TIM_CHANNEL_1);
  HAL_TIM_PWM_Start(&htim8, TIM_CHANNEL_2);
  HAL_TIM_PWM_Start(&htim8, TIM_CHANNEL_3);
  HAL_TIM_PWM_Start(&htim8, TIM_CHANNEL_4);

  // Start Enkoderów
  HAL_TIM_Encoder_Start(&htim2, TIM_CHANNEL_ALL);
  HAL_TIM_Encoder_Start(&htim3, TIM_CHANNEL_ALL);

  // Silniki zatrzymane na starcie
  pwm(0,0,0,0);
  HAL_GPIO_WritePin(GPIOC, GPIO_PIN_1, GPIO_PIN_SET);

  // Start nasłuchiwania UART
  rx_index = 0;
  HAL_UART_Receive_IT(&huart3, &rx_buffer[0], 1);
  last_cmd_time = HAL_GetTick();

  /* USER CODE END 2 */

  /* Infinite loop */
  /* USER CODE BEGIN WHILE */
  while (1)
  {
      // 1. ODBIÓR I PRZELICZENIE DANYCH Z UART
      if (new_data_flag == 1)
      {
          new_data_flag = 0;
          last_cmd_time = HAL_GetTick();

          // Obliczenie prędkości liniowych dla kół (m/s) z kinematyki
          float v_L_mps = -rxFrame.v_lin + (rxFrame.v_ang * WHEEL_BASE_M / 2.0f);
          float v_R_mps = -rxFrame.v_lin - (rxFrame.v_ang * WHEEL_BASE_M / 2.0f);

          // Przeliczenie m/s na impulsy na krok czasowy 25ms
          target_speed_L = (int)(v_L_mps * TICKS_PER_METER * DT_S);
          target_speed_R = (int)(v_R_mps * TICKS_PER_METER * DT_S);
      }

      // 2. WATCHDOG BEZPIECZEŃSTWA (Zatrzymanie przy braku komunikacji)
      /*
       if (HAL_GetTick() - last_cmd_time > TIMEOUT_MS)
      {
          target_speed_L = 0;
          target_speed_R = 0;
      }
      */

      // 3. PĘTLA REGULATORA PI (25 ms)
      if (HAL_GetTick() - prev_czas >= 25)
      {
          prev_czas = HAL_GetTick();

          // POBRANIE DANYCH Z ENKODERÓW
          current_cnt1 = (int16_t)__HAL_TIM_GET_COUNTER(&htim2);
          current_cnt2 = (int16_t)__HAL_TIM_GET_COUNTER(&htim3);

          speed1 = -(current_cnt1 - prev_licznik1);
          speed2 = (current_cnt2 - prev_licznik2);

          prev_licznik1 = current_cnt1;
          prev_licznik2 = current_cnt2;

          // PI DLA LEWEGO SILNIKA
          uchyb_L = (float)target_speed_L - (float)speed1;
          calka_L += uchyb_L;

          if (calka_L > antyWindUp) calka_L = antyWindUp;
          if (calka_L < -antyWindUp) calka_L = -antyWindUp;

          if (target_speed_L == 0) calka_L = 0; // Czyszczenie całki przy postoju

          int p1 = (int)(uchyb_L * Kp + calka_L * Ki);

          // PI DLA PRAWEGO SILNIKA
          uchyb_R = (float)target_speed_R - (float)speed2;
          calka_R += uchyb_R;

          if (calka_R > antyWindUp) calka_R = antyWindUp;
          if (calka_R < -antyWindUp) calka_R = -antyWindUp;

          if (target_speed_R == 0) calka_R = 0; // Czyszczenie całki przy postoju

          int p2 = (int)(uchyb_R * Kp + calka_R * Ki);

          // MAPOWANIE NA KANAŁY MOSTKA H (z kompensacją martwej strefy)

          // Silnik Lewy
          if (target_speed_L == 0) {
              in1 = 0; in2 = 0;
          } else if (p1 >= 0) {
              in1 = clamp(p1 + deadband, 0, 1000);
              in2 = 0;
          } else {
              in1 = 0;
              in2 = clamp(-p1 + deadband, 0, 1000);
          }

          // Silnik Prawy
          if (target_speed_R == 0) {
              in3 = 0; in4 = 0;
          } else if (p2 >= 0) {
              in3 = clamp(p2 + deadband, 0, 1000);
              in4 = 0;
          } else {
              in3 = 0;
              in4 = clamp(-p2 + deadband, 0, 1000);
          }

          // Wyślij sygnały do silników
          pwm(in1, in2, in3, in4);
      }
  }
  /* USER CODE END WHILE */
}

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
/* USER CODE BEGIN 4 */

void HAL_UART_RxCpltCallback(UART_HandleTypeDef *huart)
{
    if (huart->Instance == USART3)
    {
        if (rx_index == 0)
        {
            if (rx_buffer[0] == 0xAA) {
                rx_index = 1;
                HAL_UART_Receive_IT(&huart3, &rx_buffer[1], 9);
            } else {
                HAL_UART_Receive_IT(&huart3, &rx_buffer[0], 1);
            }
        }
        else
        {
            if (rx_buffer[9] == 0x55) {
                memcpy(&rxFrame, rx_buffer, 10);
                new_data_flag = 1;
            }
            rx_index = 0;
            HAL_UART_Receive_IT(&huart3, &rx_buffer[0], 1);
        }
    }
}

void HAL_UART_ErrorCallback(UART_HandleTypeDef *huart)
{
    if (huart->Instance == USART3)
    {
        __HAL_UART_CLEAR_OREFLAG(huart);
        __HAL_UART_CLEAR_NEFLAG(huart);
        __HAL_UART_CLEAR_FEFLAG(huart);

        rx_index = 0;
        HAL_UART_Receive_IT(&huart3, &rx_buffer[0], 1);
    }
}

/* * Obsługa przycisku w tej implementacji została opróżniona,
 * ponieważ przejmujemy pełne sterowanie po UART.
 * Możesz wykorzystać ten callback np. jako sprzętowy wyłącznik awaryjny (E-STOP).
 */
void HAL_GPIO_EXTI_Callback(uint16_t GPIO_Pin)
{
	if (GPIO_Pin == B1_Pin)
	{
		// Miejsce na logikę E-STOP
	}
}

/* USER CODE END 4 */

/**
  * @brief  Error handler
  */
void Error_Handler(void)
{
    __disable_irq();
    while (1)
    {
    }
}

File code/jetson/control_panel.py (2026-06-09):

import rclpy
from rclpy.node import Node
from std_srvs.srv import Empty
from geometry_msgs.msg import Twist
from rclpy.signals import SignalHandlerOptions
import subprocess
import os
import signal
import time
from datetime import datetime

class ControlPanel(Node):
    def __init__(self):
        super().__init__('control_panel')
        
        # Klienci do sterowania lidarem i zasilaniem Jetsona
        self.start_motor_client = self.create_client(Empty, '/start_motor')
        self.stop_motor_client = self.create_client(Empty, '/stop_motor')
        self.shutdown_jetson_client = self.create_client(Empty, '/shutdown_jetson')
        
        # Publisher do zatrzymywania robota
        self.cmd_vel_pub = self.create_publisher(Twist, '/cmd_vel', 10)
        
        # Zmienne procesów w tle
        self.slam_process = None
        self.nav2_process = None
        self.explore_process = None

        # Zmienna przechowująca referencję do aktualnego pliku logów
        self.common_log_file = None

    def call_motor(self, client, nazwa_akcji):
        print("Łączenie z Jetsonem...")
        if not client.wait_for_service(timeout_sec=3.0):
            print("Błąd: Serwis niedostępny! (Czy jetson_core działa na Jetsonie?)")
            return
        future = client.call_async(Empty.Request())
        rclpy.spin_until_future_complete(self, future)
        print(f"Polecenie wysłane na Jetsona: {nazwa_akcji}")

    def get_output_target(self):
        """Zwraca plik logów, jeśli istnieje, lub odrzuca logi, jeśli go nie ma."""
        return self.common_log_file if self.common_log_file else subprocess.DEVNULL

    def write_to_log(self, message):
        """Pomocnicza funkcja do zapisywania z datą, jeśli plik logów jest otwarty."""
        if self.common_log_file and not self.common_log_file.closed:
            timestamp = datetime.now().strftime('%H:%M:%S')
            self.common_log_file.write(f"\n[{timestamp}] {message}\n")
            self.common_log_file.flush()

    def start_slam(self):
        if self.slam_process is not None and self.slam_process.poll() is None:
            print("System SLAM już działa!")
            return
            
        print(">>> Uruchamiam system SLAM i RViz w tle...")
        self.write_to_log("--- URUCHAMIANIE SLAM ---")
        
        current_dir = os.path.dirname(os.path.realpath(__file__))
        slam_launch_file = os.path.join(current_dir, 'pc_slam.launch.py')
        
        self.slam_process = subprocess.Popen(
            ["ros2", "launch", slam_launch_file], 
            preexec_fn=os.setsid,
            stdout=self.get_output_target(),
            stderr=subprocess.STDOUT
        )

    def start_nav2(self):
        if self.nav2_process is not None and self.nav2_process.poll() is None:
            return
            
        print(">>> Uruchamiam system Nav2 w tle...")
        self.write_to_log("--- URUCHAMIANIE NAV2 ---")
        
        current_dir = os.path.dirname(os.path.realpath(__file__))
        nav2_launch_file = os.path.join(current_dir, 'pc_nav2.launch.py')
        
        self.nav2_process = subprocess.Popen(
            ["ros2", "launch", nav2_launch_file], 
            preexec_fn=os.setsid,
            stdout=self.get_output_target(),
            stderr=subprocess.STDOUT
        )

    def start_exploration(self):
        if self.explore_process is not None and self.explore_process.poll() is None:
            return
            
        print(">>> Uruchamiam system Explore Lite (Autonomiczna Eksploracja)...")
        self.write_to_log("--- URUCHAMIANIE M-EXPLORE ---")
        
        self.explore_process = subprocess.Popen(
            ["ros2", "launch", "explore_lite", "explore.launch.py"], 
            preexec_fn=os.setsid,
            stdout=self.get_output_target(),
            stderr=subprocess.STDOUT
        )

    def stop_slam(self):
        print(">>> Zatrzymuję system SLAM...")
        if self.slam_process:
            try:
                os.killpg(os.getpgid(self.slam_process.pid), signal.SIGINT)
                self.slam_process.wait(timeout=5.0)
            except Exception:
                pass
            self.slam_process = None
                
        subprocess.run(["pkill", "-9", "-f", "slam_toolbox"], stderr=subprocess.DEVNULL)
        subprocess.run(["pkill", "-9", "-f", "rf2o_laser_odometry"], stderr=subprocess.DEVNULL)
        subprocess.run(["pkill", "-9", "-f", "rviz2"], stderr=subprocess.DEVNULL)

    def stop_nav_systems(self):
        print(">>> Zatrzymuję systemy Nawigacji i Eksploracji...")
        
        # Zatrzymywanie Nav2
        if self.nav2_process:
            try:
                os.killpg(os.getpgid(self.nav2_process.pid), signal.SIGINT)
                self.nav2_process.wait(timeout=5.0)
            except Exception:
                pass
            self.nav2_process = None
                
        # Zatrzymywanie Explore Lite
        if self.explore_process:
            try:
                os.killpg(os.getpgid(self.explore_process.pid), signal.SIGINT)
                self.explore_process.wait(timeout=5.0)
            except Exception:
                pass
            self.explore_process = None

        subprocess.run(["pkill", "-9", "-f", "component_container"], stderr=subprocess.DEVNULL)
        subprocess.run(["pkill", "-9", "-f", "explore"], stderr=subprocess.DEVNULL)
        
    def stop_robot(self):
        msg = Twist()
        msg.linear.x = 0.0
        msg.angular.z = 0.0
        self.cmd_vel_pub.publish(msg)
        print("[PANEL] Wysłano sygnał stopu (Prędkość wyzerowana).")
    
    def shutdown_system(self):
        print("\n[ZAMYKANIE] Czyszczenie procesów na PC...")
        self.stop_nav_systems()
        self.stop_slam()
        self.stop_robot()
        subprocess.run(["pkill", "-9", "-f", "teleop_twist_keyboard"], stderr=subprocess.DEVNULL)
        
        # Bezpieczne zamknięcie pliku, jeśli był otwarty
        if self.common_log_file and not self.common_log_file.closed:
            self.write_to_log("=== KONIEC SESJI PANELU ===")
            self.common_log_file.close()
            
        print("Gotowe. Do widzenia!")
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

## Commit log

2026-05-08 added uartTest code
2026-05-21 added platform_v3 3D model
    [Part22.SLDPRT, lowPlatform_v3.stl, low_platform_v1.1.stl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]
2026-05-21 add diodeButtonTest code
2026-05-21 update ver2 code config.txt
    [configuration.txt]
2026-05-21 update pcb submodule
2026-05-25 add up_platform v3 3D model
    [up_platform_v3.stl]
2026-05-27 add up_platform_v4 3D model
    [up_platform_v4.stl]
2026-05-27 add enkoderTest code
    [configuration.txt]
2026-05-27 add engineTest code
    [configuration.txt]
2026-05-28 component list
    [lista komponentów 2.xlsx]
2026-05-29 ver1 code update for new platform
    [configuration.txt]
2026-05-29 uartTest code update + code README revised
    [component list 2.xlsx, configuration.txt]
2026-05-29 add up_platform_v5 3D model
    [up_platform_v5.stl]
2026-05-29 Simulation to test Kalman filter
2026-05-31 code ver2 directions change
    [configuration.txt]
2026-05-31 code ver2 fixes + diode
    [main.c]
2026-05-31 clean up
    [component list 2.xlsx]
2026-06-01 updated power balance
2026-06-01 add pcb schemat photo
2026-06-04 dosc: add wiring diagriam_v3
2026-06-04 dosc: update driver in power balance
2026-06-04 fix: control_panel auto turn off
    [control_panel.py]
2026-06-04 code ver3 robot orientation fix
    [main.c]
2026-06-05 fix: modified dwa config to avoid robot geting stuck
    [dwa.py, robot_navigation.py]
2026-06-06 Return to standard lidar orientation
2026-06-06 STM32 code cleanup
2026-06-08 add robot assembly 3d model
2026-06-08 jetson autonomic navigatino nav2 fix
    [control_panel.py, robot_navigation.py, uart_bridge.py]
2026-06-08 add robot-assembly-simplified
    [12.STEP, Part22.SLDPRT, robot-assembly-simplified.stl]
2026-06-08 add platform 3d models
    [assist-wheel.stl, battery-pack.stl, low-platform.stl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]
2026-06-08 add components 3d models
    [12.STEP, Part22.SLDPRT, battery-pack.stl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]
2026-06-08 ESP32 code clean up
2026-06-13 chore: add sample-map image
2026-06-16 chore: 3D models clean up
    [robot-assembly-simplified.stl]
